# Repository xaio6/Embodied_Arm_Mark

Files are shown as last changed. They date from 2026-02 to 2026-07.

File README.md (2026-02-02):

# HorizonArm Mark 版本

欢迎使用 **HorizonArm Mark 版本**开发包。本文档是**根目录总入口**：用“学习路线”的方式，带你从 0 到 1 跑通示例，再按你的角色（控制/视觉/AI/仿真/交互）逐步深入，最终把 SDK 稳定集成进你的项目。

> 强烈建议：不要只“看文档”，要**边看边运行示例**。本仓库已经把“可复制、可运行、可扩展”的示例准备好了。

---

## 🎯 学习路线总览（按路线走，不迷路）

```text
第0步：了解项目结构（5分钟）
    ↓
第1步：环境准备与安装依赖（10分钟）
    ↓
第2步：SDK 理论学习（30分钟）
    ↓
第3步：5分钟跑通快速入门（5分钟）
    ↓
第4步：按角色选择深入学习路径（2-8小时）
    ↓
第5步：项目实践与工程化集成（持续迭代）
```

---

## 📂 第0步：了解项目结构（5分钟）

本仓库的“真正入口”在 `example/`：**示例 + 文档 + 学习路径**都在里面。

```text
Horizon_Arm_Mark/
├── example/                              ⭐ 从这里开始（示例与文档总入口）
│   ├── README.md                         - 示例总导航（第一次打开就看它）
│   ├── SDK完全介绍.md                     - SDK 架构与核心概念（强烈建议先看）
│   ├── 示例代码总导航.md                  - 更细粒度的示例索引与学习路径
│   ├── quickstart_guide.py               - 5分钟快速入门（强烈建议先跑）
│   ├── sdk_quickstart.py                 - 交互式完整示例（6轴/预设动作/夹爪等）
│   ├── control_sdk_examples/             - 控制相关教学示例（单电机/多机同步/IO/视觉/仿真/手柄）
│   ├── ai_sdk_examples/                  - AI 相关示例（LLM/ASR/TTS/多模态/智能对话）
│   ├── developer_tools/                  - 开发者工具（传感器监控/仿真滑块等）
│   ├── docs/                             - 文档中心（index.md 是总入口）
│   └── mkdocs.yml                        - 文档站点配置（如需自行构建）
│
├── Embodied_SDK/                          ⭐ 推荐开发入口（Python 源码，可直接读/改/引用）
│   ├── horizon_sdk.py                     - 顶层聚合入口（HorizonArmSDK）
│   ├── motion.py                          - 运动控制（关节/笛卡尔/预设动作/夹爪等）
│   ├── visual_grasp.py                    - 视觉抓取/跟随
│   ├── joycon.py                          - 手柄控制封装（如需）
│   ├── io.py                              - IO 控制
│   ├── digital_twin.py                    - MuJoCo 仿真接口（如需）
│   ├── ai.py                              - AI 封装（如需）
│   └── __init__.py                        - 常用导出（create_motor_controller 等）
│
├── Horizon_Core/                          🔒 核心驱动与算法（部分为二进制封装 .pyd）
│   ├── Control_SDK/                       - 控制核心与协议层
│   ├── AI_SDK/                            - AI 核心（providers/core/utils 等）
│   └── gateway.py                         - 常用网关入口（部分示例会引用）
│
├── config/                                ⚙️ 配置文件（电机/标定/URDF/AI/预设动作等）
│   ├── motor_config.json
│   ├── calibration_parameter.json
│   ├── embodied_config/preset_actions.json
│   ├── aisdk_config.yaml
│   └── urdf/mjmodel.xml                   - 仿真模型（MuJoCo）
│
├── requirements.txt                        📄 依赖清单（已按“默认必装/可选”分组）
└── README.md                               📖 你正在读的文档（Mark 版本总入口）
```

你需要记住的只有两句话：

- **想快速跑起来**：直接看并运行 `example/quickstart_guide.py`
- **想系统学/做项目**：从 `example/README.md` 与 `example/docs/index.md` 开始走路线

---

## 🔧 第1步：环境准备与安装依赖（10分钟）

### 1.1 环境要求

- **Python**：3.12+（本仓库示例与依赖分组以此为准）
- **操作系统**：Windows 10/11（也可 Ubuntu 20.04+ 纯脚本运行）
- **真实硬件（可选）**：OmniCAN（UCP 模式，电脑侧表现为串口）+ 机械臂驱动板/电机

### 1.2 安装依赖（推荐）

在项目根目录执行：

```bash
pip install -r requirements.txt
```

`requirements.txt` 的设计原则：

- **默认必装**：能跑通“控制 + 视觉”核心示例
- **可选依赖**：Joy-Con / AI / 语音 / MuJoCo / GUI / 可视化等，按需启用

> 如果你只想先控制机械臂、跑运动示例：默认安装即可；不要一上来就把所有可选功能都装齐。

### 1.3 Windows 下常见安装问题（可选项）

- **pyaudio（仅语音相关示例需要）**：部分环境需要额外步骤  
  参考 `requirements.txt` 里的说明（例如 `pipwin install pyaudio`）。

---

## 📚 第2步：SDK 理论学习（30分钟）

### 2.1 必读文档（强烈建议）

- **SDK 架构与示例索引**：`example/SDK完全介绍.md`
- **文档中心总入口**：`example/docs/index.md`

阅读目标（30 分钟内达成）：

- 知道推荐入口是 `Embodied_SDK`，顶层入口是 `HorizonArmSDK`
- 理解两套常用坐标/单位：  
  - 关节角：度（deg）  
  - 末端位置：毫米（mm）；末端姿态：度（deg）
- 知道你应该先跑哪些示例、下一步该学哪些模块文档

---

## 🚀 第3步：5分钟跑通快速入门（5分钟）

### 3.1 ⚠️ 安全第一（务必先读）

第一次上电、第一次跑控制脚本前，先看：

- `example/docs/safety.md`

其中最关键的一条（请务必理解）：

- **如果你的电机没有物理抱闸（刹车），严禁随意 `disable()` 失能**  
  正确做法通常是 **stop（停止运动）/disconnect（断开通信）**，而不是让机械臂“瞬间掉落”。

### 3.2 运行快速入门脚本

直接在根目录运行：

```bash
python example/quickstart_guide.py
```

你会做的事情（典型流程）：

- 输入/确认串口号（Windows 设备管理器里看到的 `COMx`）
- 连接电机（通常是 1-6 号关节；夹爪可能是 7 号，视你的硬件）
- 读取状态、执行小幅度运动验证链路

### 3.3 跑通后继续：完整交互示例

```bash
python example/sdk_quickstart.py
```

这个脚本更像“控制台版上位机”，适合用来：

- 复习关节运动 / 笛卡尔运动
- 测试夹爪与预设动作
- 在你写自己项目之前，先把基础能力跑顺

---

## 🎓 第4步：按角色选择深入学习路径（2-8小时）

> 更完整导航请直接看：`example/README.md` 与 `example/示例代码总导航.md`  
> 文档中心请看：`example/docs/index.md`

下面按真实开发角色给你“最短路径”，每一步都能落到仓库里**真实存在的文件**。

---

### 🔧 路径A：机械臂控制工程师（4-6小时）

**目标**：掌握电机控制、运动、同步控制、IO 联动，并具备工程化集成能力。

#### A1. 单电机与基础通信（30-60分钟）

- `example/control_sdk_examples/motor_usage_example.py`
- 完整参考（功能更多）：`example/test_interactive.py`

你需要掌握：

- 连接/断开（connect/disconnect）
- 停止（stop）与“失能（disable）”的安全区别（见 `example/docs/safety.md`）
- 位置/速度/力矩模式的基本用法（示例里都有）

#### A2. 6轴基础运动与预设动作（30-60分钟）

- `example/sdk_quickstart.py`
- 文档：`example/docs/motion.md`

你需要掌握：

- `move_joints`（关节空间）
- `move_cartesian`（笛卡尔空间）
- 预设动作的组织方式（`config/embodied_config/preset_actions.json`）

#### A3. 多电机同步（20-60分钟）

- 教学版：`example/control_sdk_examples/multi_motor_sync_example.py`
- 完整版：`example/test_multi_motor_sync.py`

你需要掌握：

- 同步控制的基本思想：一次性下发/触发/执行（示例会解释）
- 如何选择“教学版”与“完整版”（先学教学版，再看完整版）

#### A4. IO 集成（20-40分钟）

- `example/control_sdk_examples/io_control_example.py`
- 文档：`example/docs/io.md`

适用场景：

- 传感器触发（限位、光电、接近等）
- 执行器联动（继电器、气动、电磁阀、指示灯等）

#### A5. 工程化落地建议（你写项目时最常踩坑的点）

建议你在自己项目里做到：

- 把串口号、相机 ID、电机 ID 列表、速度/加速度、工作空间限制等全部做成可配置项
- 写“安全启动流程”：上电 → 自检 → 低速小幅度试动 → 正式运行
- 写“统一退出流程”：异常时 stop + disconnect（不要直接 disable）

---

### 👁️ 路径B：视觉应用开发者（3-5小时）

**目标**：掌握标定文件、像素到机械臂坐标、视觉抓取/跟随的基本流程，并能排查“抓不准”。

#### B1. 先把基础控制跑通（30分钟）

- `example/quickstart_guide.py`
- `example/control_sdk_examples/motor_usage_example.py`

#### B2. 视觉抓取示例（1-2小时）

- `example/control_sdk_examples/visual_grasp_example.py`
- 文档：`example/docs/vision.md`

你需要关注的配置与文件：

- `config/calibration_parameter.json`（标定参数）
- 视觉相关示例通常会做“自检”（是否存在标定文件等），建议先看输出再动手修改参数

#### B3. 常见问题与排查思路（很重要）

如果出现“抓取位置偏差大”，优先排查：

- 标定文件是否对应当前相机与安装位姿（换相机/换安装位置必须重标定或更新参数）
- TCP 偏移、抓取高度/接近高度是否合理（过低容易碰撞，过高会抓不到）
- 视觉输入的像素点是否来自同一分辨率/同一相机 ID

文档入口：

- `example/docs/troubleshooting.md`
- `example/docs/configuration.md`

---

### 🧠 路径C：AI 集成开发者（4-6小时）

**目标**：能跑通 AI 配置与示例，理解“AI 输出如何安全地驱动机械臂动作”，并能做基础的工程集成。

#### C1. 先理解配置（30-60分钟）

- `example/ai_sdk_examples/config_example.py`
- 配置文件：`config/aisdk_config.yaml`

#### C2. LLM / 多模态 / 语音（按需选择）

- LLM：`example/ai_sdk_examples/LLM_usage.py`
- 多模态：`example/ai_sdk_examples/multimodal_usage_example.py`
- 语音识别：`example/ai_sdk_examples/asr_usage_example.py`
- 语音合成：`example/ai_sdk_examples/tts_usage_example.py`
- 综合 Demo：
  - `example/ai_sdk_examples/smart_multimodal_chat_demo.py`
  - `example/ai_sdk_examples/smart_multimodal_voice_chat_demo.py`

#### C3. 具身智能（建议先在仿真验证，再上真机）

- 文档：`example/docs/embodied.md`

安全建议（强烈建议你遵守）：

- AI 输出必须做约束（速度、空间、姿态范围、动作类型白名单）
- 先在仿真/离线环境验证，再在真机小幅度、低速尝试

---

### 🎮 路径D：人机交互开发者（3-4小时）

**目标**：把“输入设备/交互逻辑/安全停止/状态显示”做成你能复用的交互组件。

仓库入口（按需选择）：

- 手柄文档：`example/docs/joycon.md`
- 手柄教学示例：`example/control_sdk_examples/joycon_control_example.py`
- 全功能控制台参考：`example/test_joycon_arm_control.py`
- 状态可视化：`example/test_joycon_display.py`

开发者工具（调试很有用）：

- `example/developer_tools/README.md`
- `example/developer_tools/joycon_sensor_display.py`

---

### 🎮 路径E：仿真开发者（1-2小时）

**目标**：在没有真实硬件时也能开发；在上真机前先验证轨迹/动作逻辑。

入口：

- 教学示例：`example/control_sdk_examples/digital_twin_example.py`
- 交互演示：`example/mujoco_control.py`
- 文档：`example/docs/simulation.md`

关键文件：

- `config/urdf/mjmodel.xml`

---

## 🛠️ 第5步：项目实践与工程化集成（持续）

这一部分是“从示例到你项目”的落地建议：字多但很实用，建议你在真正写业务代码前扫一遍。

---

### 5.1 推荐的项目集成方式（强烈建议照抄结构）

你可以在仓库根目录旁边新建自己的项目目录，例如：

```text
my_mark_project/
├── app/                         # 你的业务逻辑
│   ├── main.py
│   ├── robot/                   # 机械臂封装层（你自己写）
│   ├── vision/                  # 视觉封装层（你自己写）
│   └── io/                      # IO 封装层（你自己写）
├── configs/
│   └── config_local.yaml        # 你自己的部署参数（端口/相机ID/速度等）
└── README.md
```

并且把仓库里的 SDK 当作“依赖/子模块/同仓引用”，而不是把示例代码散落复制到各处。

---

### 5.2 你必须配置化的参数（不然一定会痛苦）

建议至少把这些参数全部配置化（配置文件/环境变量/命令行参数任选其一）：

- 串口号：`COMx`
- 电机 ID 列表：默认 1-6（夹爪可能是 7）
- 相机 ID：`camera_id`（默认 0）
- 最大速度、加速度、减速度（首次使用务必低速）
- 预设动作名称与对应关节角（`preset_actions.json`）
- 视觉抓取参数（抓取高度、接近高度、TCP 偏移等）
- 工作空间限制（半径/高度/禁区）

---

### 5.3 运行与部署（建议习惯性做的检查）

每次上线/每次更换环境，建议你都做一次“最小验证”：

1. 先跑 `example/quickstart_guide.py`（确认通信链路 OK）
2. 再跑 `example/sdk_quickstart.py`（确认 6 轴基本动作 OK）
3. 再跑你自己的业务脚本（逐步扩大动作范围）

为什么要这么做：

- 能快速区分是“硬件/连接问题”还是“你业务代码问题”
- 能避免“第一次就跑你的复杂业务”导致无法定位问题

---

### 5.4 故障排查的最短路径（别乱猜）

文档入口：

- `example/docs/troubleshooting.md`

最常见的 5 类问题与优先级：

1. **串口打不开**：端口号不对 / 被占用 / 设备驱动问题
2. **电机无响应**：ID 不对 / 供电问题 / 总线问题
3. **运动方向不对**：检查 `config/motor_config.json` 里的方向/减速比等
4. **视觉抓不准**：标定文件不匹配 / TCP 偏移不对 / 分辨率/相机 ID 不一致
5. **仿真起不来**：`mujoco` 未安装 / OpenGL 环境问题 / 模型文件缺失

---

## 📖 文档与资源索引（快速跳转）

### 你应该优先打开的 3 个入口

- `example/README.md`（示例总导航）
- `example/SDK完全介绍.md`（架构与核心概念）
- `example/docs/index.md`（文档中心总入口）

### 常用文档

- 安装：`example/docs/installation.md`
- 安全：`example/docs/safety.md`
- 快速入门：`example/docs/quickstart.md`
- 配置说明：`example/docs/configuration.md`
- API 参考：`example/docs/api_reference.md`
- API 详细：`example/docs/api_detailed.md`
- 故障排查：`example/docs/troubleshooting.md`

---

## 🧾 版本信息

- **版本**：Mark（Horizon_Arm2.0）
- **更新时间**：2026-02
- **维护**：HorizonArm Team

#

## 📊 学习进度自检表

根据您的学习目标，勾选已完成的项目：

### 🎯 基础掌握（所有开发者必须）

- [ ] 理解SDK架构和9个核心模块
- [ ] 成功连接一台电机
- [ ] 能够控制电机运动（速度/位置）
- [ ] 理解关节空间和笛卡尔空间
- [ ] 能够查阅示例代码并复用

### 🔧 控制工程师进阶

- [ ] 掌握单电机全部控制模式
- [ ] 实现多机同步控制
- [ ] 理解同步控制三阶段
- [ ] 集成IO传感器和执行器
- [ ] 能够调试电机参数（PID等）

### 👁️ 视觉开发者进阶

- [ ] 理解手眼标定原理
- [ ] 成功执行像素点抓取
- [ ] 实现视觉跟随功能
- [ ] 结合AI进行目标识别
- [ ] 能够独立进行相机标定

### 🤖 交互开发者进阶

- [ ] 配对并连接Joy-Con
- [ ] 实现手柄遥操作
- [ ] 配置自定义按键映射
- [ ] 实现IO联动控制
- [ ] 集成语音交互（可选）

### 🧠 AI开发者进阶

- [ ] 配置AI SDK
- [ ] 调用LLM API
- [ ] 实现多模态理解
- [ ] 集成语音识别和合成
- [ ] 实现AI驱动的机械臂控制

---

## 🆘 常见问题和解决方案

### Q1: 电机连接失败？

**检查清单：**
1. 串口号是否正确（设备管理器查看）
2. 电机ID是否正确
3. 电机是否上电
4. 没有其他程序占用串口

**参考：** `example/SDK完全介绍.md` 的"常见问题"部分或 `example/docs/troubleshooting.md`

### Q2: 多电机控制失败？

**解决方案：**
必须使用 `shared_interface=True`：
```python
for mid in [1, 2, 3, 4, 5, 6]:
    motor = create_motor_controller(motor_id=mid, shared_interface=True)
```

### Q3: 视觉抓取位置不准？

**检查：**
1. 是否完成手眼标定
2. 标定文件路径是否正确
3. 相机和机械臂位置是否改变

### Q4: 授权验证失败？

**联系技术支持获取授权文件**

---

## 📖 文档索引

### 核心文档

| 文档 | 位置 | 用途 |
|---|---|---|
| **开发者学习路线** | `开发者学习路线.md` | 本文档 - 完整学习路线 |
| **SDK完全介绍** | `example/SDK完全介绍.md` | SDK详细文档和架构说明 |
| **示例代码总导航** | `example/示例代码总导航.md` 或 `example/README.md` | 示例导航和快速开始 |
| **Control SDK指南** | `example/control_sdk_examples/README.md` | Control SDK学习路径 |
| **文档中心** | `example/docs/index.md` | 完整文档导航 |

### 示例代码

| 类型 | 位置 | 说明 |
|---|---|---|
| 快速入门 | `example/quickstart_guide.py` | 5分钟体验 |
| Control SDK | `example/control_sdk_examples/` | 7个教学示例 |
| AI SDK | `example/ai_sdk_examples/` | 10+个AI示例 |
| 完整参考 | `example/test_*.py` | 40+功能完整版 |
| 开发工具 | `example/developer_tools/` | 调试工具 |

---

## 🎓 学习建议

### 时间安排

- **兼职学习**：每天1-2小时，1周内完成基础路径
- **全职学习**：每天4-6小时，2-3天内完成基础路径
- **深入掌握**：持续2-4周，完成所有进阶内容

### 学习方法

1. **理论与实践结合**
   - 先看文档理解原理
   - 立即运行示例验证
   - 修改参数加深理解

2. **循序渐进**
   - 不要跳过基础内容
   - 按推荐顺序学习
   - 每个示例都要运行

3. **查看源码**
   - `Embodied_SDK/` 源码可以查看
   - 理解API实现逻辑
   - 学习代码组织方式

4. **动手实践**
   - 完成自检表中的所有项目
   - 尝试实现小项目
   - 遇到问题主动排查

---

## 📞 技术支持

遇到问题？按以下顺序解决：

1. **查看文档** - `example/SDK完全介绍.md` 的常见问题部分
2. **查看故障排除** - `example/docs/troubleshooting.md` 详细的故障诊断
3. **运行自检** - 相关示例的系统自检功能
4. **查看完整示例** - `example/test_interactive.py` 等完整版参考
5. **使用调试工具** - `example/developer_tools/` 下的专业工具
6. **联系技术支持** - 提供详细错误信息和日志

---

## 🎯 学习目标检验

### 基础能力（所有开发者必备）

完成基础学习后，您应该能够：

- ✅ **连接控制** - 独立连接和控制单个或多个电机
- ✅ **理解架构** - 理解SDK的模块组织和调用关系
- ✅ **查阅文档** - 能够快速查阅文档找到需要的API
- ✅ **复用代码** - 复用示例代码到自己的项目中
- ✅ **排查问题** - 能够根据错误信息初步排查问题
- ✅ **配置管理** - 理解和修改配置文件

### 进阶能力（根据专业方向）

#### 🔧 控制工程师
- ✅ 掌握三种电机控制模式（速度/位置/力矩）
- ✅ 实现多电机精确同步控制
- ✅ 集成IO传感器和执行器
- ✅ 调试和优化运动参数（PID等）
- ✅ 处理异常情况和安全保护

#### 👁️ 视觉开发者
- ✅ 理解手眼标定原理和流程
- ✅ 实现像素坐标到机械臂坐标转换
- ✅ 完成视觉引导抓取任务
- ✅ 集成AI进行目标识别和分类
- ✅ 优化视觉处理性能

#### 🤖 交互开发者
- ✅ 配置和使用Joy-Con手柄控制
- ✅ 自定义按键映射和控制参数
- ✅ 实现IO联动和传感器触发
- ✅ 集成语音识别和合成（可选）
- ✅ 设计直观的人机交互界面

#### 🧠 AI开发者
- ✅ 配置和调用LLM API
- ✅ 实现多模态理解（视觉+语言）
- ✅ 集成语音识别和语音合成
- ✅ 实现AI驱动的机械臂控制
- ✅ 设计具身智能应用

### 专家能力（高级开发者目标）

- ✅ **深入理解** - 理解SDK底层实现原理和通信协议
- ✅ **扩展开发** - 自定义扩展功能和新模块
- ✅ **性能优化** - 优化系统性能和稳定性
- ✅ **系统集成** - 集成到复杂的生产系统中
- ✅ **架构设计** - 设计大型机械臂应用的软件架构
- ✅ **问题诊断** - 快速诊断和解决复杂问题

---

## 📈 进阶学习资源

### 源码学习
- **Embodied_SDK/** - SDK源码可查看，学习实现原理
- **关键文件**:
  - `motion.py` - 运动学算法实现
  - `visual_grasp.py` - 手眼标定和坐标转换
  - `joycon.py` - 手柄控制映射逻辑
  - `digital_twin.py` - MuJoCo仿真接口

### 配置文件
- **config/** - 各种配置示例
  - `motor_config.json` - 电机参数配置
  - `calibration_parameter.json` - 标定参数
  - `aisdk_config.yaml` - AI服务配置
  - `preset_actions.json` - 预设动作定义

### 完整示例
- **test_interactive.py** - 40+功能的完整单电机工具
- **test_multi_motor_sync.py** - 26+功能的多机同步工具
- **sdk_quickstart.py** - 完整的机械臂控制框架

---

## 🎓 认证与考核（可选）

### 基础认证
完成以下任务即可认为掌握基础能力：
1. 独立编写程序连接并控制6个电机
2. 实现多电机同步运动
3. 集成一个IO传感器
4. 处理连接失败等异常情况

### 进阶认证
根据您的专业方向完成对应项目：
- **控制工程师**: 实现一个完整的自动化流程
- **视觉开发者**: 实现一个视觉引导抓取任务
- **交互开发者**: 实现一个手柄遥操作系统
- **AI开发者**: 实现一个自然语言控制的机械臂

---

## 🌟 成功案例参考

### 案例1：自动化生产线
- **应用**: 产品分拣和装配
- **技术栈**: 电机控制 + IO联动 + 视觉检测
- **学习时间**: 2周
- **关键技术**: 多机同步、IO触发、位置精度控制

### 案例2：智能服务机器人
- **应用**: 物品识别和递送
- **技术栈**: 视觉抓取 + AI识别 + 语音交互
- **学习时间**: 3周
- **关键技术**: 手眼标定、目标检测、自然语言理解

### 案例3：远程遥操作系统
- **应用**: 危险环境作业
- **技术栈**: 手柄控制 + 视觉反馈 + 力反馈
- **学习时间**: 2周
- **关键技术**: 实时控制、视频传输、安全保护

### 案例4：算法研究平台
- **应用**: 运动规划算法验证
- **技术栈**: 数字孪生 + 轨迹规划
- **学习时间**: 1周
- **关键技术**: MuJoCo仿真、逆运动学、碰撞检测

---

## 💪 持续成长建议

### 技术提升
- 📚 **阅读论文** - 了解机械臂和机器人领域前沿技术
- 💻 **开源贡献** - 参与相关开源项目
- 🎯 **实战项目** - 完成实际应用项目积累经验
- 🤝 **技术交流** - 参加技术社区和开发者交流

### 知识扩展
- **机械臂运动学** - 深入学习正逆运动学理论
- **计算机视觉** - 学习图像处理和目标识别
- **控制理论** - 学习PID控制和高级控制算法
- **AI技术** - 学习深度学习和强化学习

### 职业发展
- **机械臂应用工程师** - 负责机械臂系统集成和应用开发
- **机器人视觉工程师** - 专注于视觉引导和AI识别
- **自动化系统架构师** - 设计大型自动化系统
- **具身智能研究员** - 研究AI与机器人结合

---

**版本**: Mark  
**更新日期**: 2026-1  
**维护**: HorizonArm  

祝您学习顺利，成为优秀的机械臂开发者！🚀  
如有任何问题，欢迎查阅文档或联系技术支持。

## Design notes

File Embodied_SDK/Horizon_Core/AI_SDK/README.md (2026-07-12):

# AI_SDK 开发者文档

AI_SDK 提供一个统一、简洁的 Python 接口，聚合多家 AI 能力：
- LLM 大语言模型（聊天/流式/异步/上下文会话）
- ASR 语音识别（文件/麦克风/实时流/关键词唤醒）
- TTS 语音合成（文件/扬声器/流式边听边说）
- 多模态（图像/视频理解，多图像分析）
- 智能对话（LLM + TTS 一体化）

面向“应用层开发者”：你只需调用 SDK 方法，不需要了解底层供应商的差异和协议细节。

---

## 安装与环境

- 推荐直接使用项目根目录的依赖：
  ```bash
  pip install -r requirements.txt
  ```
- Windows 安装 `pyaudio` 可能需要：
  ```bash
  pip install pipwin && pipwin install pyaudio
  ```

## 配置（强烈建议用环境变量注入密钥）

默认读取 `config/aisdk_config.yaml`，也可传入 `config_dict`。建议将密钥以环境变量形式配置，例如：

```yaml
providers:
  alibaba:
    api_key: ${ALI_API_KEY}
    default_params:
      max_tokens: 2000
      temperature: 0.7
      top_p: 0.8
    enabled: true
  deepseek:
    api_key: ${DEEPSEEK_API_KEY}
    default_params:
      max_tokens: 2000
      temperature: 0.7
      top_p: 1.0
    enabled: true
```

- 支持覆盖的常见配置：
  - `request`: `timeout`, `max_retries`, `retry_delay`
  - `logging`: `level`, `file`, `max_size`, `backup_count`
  - `session`: `default_max_history`, `max_sessions`
  - `providers.*.default_params`: 每家默认模型参数（`temperature`, `top_p`, `max_tokens` 等）

---

## 快速开始

```python
from Embodied_SDK import AISDK

sdk = AISDK()  # 默认读取 config/aisdk_config.yaml

# 1) 基础聊天（同步）
resp = sdk.chat(provider="alibaba", model="qwen-turbo", prompt="你好")
print(resp)

# 2) 流式聊天（同步流）
for chunk in sdk.chat("alibaba", "qwen-turbo", "讲个笑话", stream=True):
    print(chunk, end="")

# 3) 上下文对话（自动管理历史）
sdk.chat("alibaba", "qwen-turbo", "我叫张三", use_context=True)
name = sdk.chat("alibaba", "qwen-turbo", "我叫什么？", use_context=True)

# 4) 异步调用（需在异步环境中）
# response = await sdk.chat("alibaba", "qwen-turbo", "你好", async_mode=True)
```

---

## ASR 语音识别

```python
# 文件识别
r = sdk.asr(provider="alibaba", mode="file", audio_file="audio.wav")

# 麦克风识别（duration: 秒）
r = sdk.asr("alibaba", "microphone", duration=5)

# 实时流识别（传入音频流/生成器）
for out in sdk.asr("alibaba", "stream", audio_stream=my_stream()):
    print(out)

# 关键词检测（流式唤醒）
for out in sdk.asr("alibaba", "keyword", keywords=["你好", "小助手"]):
    if out.get("success"):
        print("唤醒词：", out.get("keyword_detected"))
```

常用参数：`audio_file`、`duration`、`audio_stream`、`keywords`、`async_mode` 等。

---

## TTS 语音合成

```python
# 文本转语音 → 保存到文件
r = sdk.tts(provider="alibaba", mode="file", text="你好世界", output_file="out.mp3")

# 文本转语音 → 扬声器播放
r = sdk.tts("alibaba", "speaker", "欢迎使用AI_SDK")

# 流式合成（配合LLM流式输出或自定义生成器）
def text_gen():
    yield "今天天气"
    yield "不错"
for r in sdk.tts("alibaba", "stream", text_gen()):
    print("chunk done")
```

常用参数：`voice`, `sample_rate`, `format`, `speaker`, `prosody` 等（依具体提供商/模型）。

---

## 多模态（图像/视频）

```python
# 图像理解
r = sdk.multimodal(provider="alibaba", mode="image", prompt="描述这张图", image_path="image.jpg")

# 视频分析
r = sdk.multimodal("alibaba", "video", "这个视频讲了什么", video_path="video.mp4")

# 多图像分析
r = sdk.multimodal("alibaba", "multiple_images", "比较这些图片", image_paths=["a.jpg", "b.jpg"])  # 通过kwargs传入
```

常用参数：`model`（如 `qwen-vl-max-latest`）、`temperature`、`max_tokens`、`fps`（视频抽帧）等。

---

## 智能对话（LLM + TTS 一体化）

```python
# 直接问答并语音播放
o = sdk.smart_chat(
    prompt="请用两句话介绍一下你自己",
    llm_provider="alibaba", llm_model="qwen-turbo",
    tts_provider="alibaba", tts_model="sambert-zhichu-v1",
    tts_mode="speaker",  # 或 "file"/"stream"
    use_context=False,
)
print(o)
```

进阶：`smart_multimodal_chat`（图像/视频 + 文本）、`smart_voice_chat`（语音端到端）、`smart_multimodal_voice_chat`。

---

## 会话与上下文

```python
# 使用默认全局历史
sdk.chat("alibaba", "qwen-turbo", "记住我叫王五", use_context=True)

# 自定义会话ID
a_id = "user_A"
sdk.create_session(session_id=a_id, max_history=30)
sdk.chat("alibaba", "qwen-turbo", "我喜欢足球", use_context=True, session_id=a_id)

# 历史管理
hist = sdk.get_conversation_history(session_id=a_id)
sdk.set_conversation_history(hist[-10:], session_id=a_id)
sdk.clear_conversation_history(session_id=a_id)

# 会话管理
sdk.list_sessions()
sdk.delete_session(a_id)
```

---

## 切换提供商与模型

```python
# 查看可用提供商
deps = sdk.get_available_providers()

# 查看提供商可用模型
models = sdk.get_provider_models("alibaba")

# 在同一套API下切换到DeepSeek
o = sdk.chat(provider="deepseek", model="deepseek-chat", prompt="Explain RAG in 1 sentence")
```

你也可以在 `config/aisdk_config.yaml` 中启用/禁用提供商或修改 `default_params`。

---

## 异步与流式

- 任意接口均可设置 `async_mode=True` 获得 `await` 版本
- LLM 与 TTS 支持 `stream=True` 或对应的流式生成器

```python
# 异步流式
# async for chunk in sdk.chat("alibaba", "qwen-turbo", "你好", stream=True, async_mode=True):
#     print(chunk)
```

---

## 错误处理与日志

```python
from Embodied_SDK.Horizon_Core.AI_SDK.utils.exceptions import AISDKException

try:
    sdk.chat("alibaba", "qwen-turbo", "hi")
except AISDKException as e:
    print("AI错误:", str(e))
except Exception as e:
    print("其他错误:", str(e))
```

- 日志：在 `config/aisdk_config.yaml` 的 `logging` 中配置输出文件、级别与大小滚动。

---

## 目录结构（简要）

```
AI_SDK/
├── __init__.py                 # AISDK 主入口（统一API）
├── core/                       # 领域处理器（llm/asr/tts/multimodal/smart_chat/session等）
├── services/                   # 面向AISDK的服务封装
├── providers/                  # 各家厂商适配（alibaba、deepseek等）
├── utils/                      # 异常、工具、格式化等
└── README.md                   # 本文档
```

---

## 最佳实践

- 使用环境变量注入 API Key（不要把密钥提交到仓库）：
  - Windows PowerShell: `setx ALI_API_KEY "your_key"`
  - Linux/macOS: `export ALI_API_KEY=your_key`
- 覆盖默认配置：初始化时传 `config_dict` 或修改 YAML 中的 `default_params`。
- 控制并发与重试：通过 `request.max_retries`、`timeout`、`retry_delay` 调整。
- 资源清理：处理长会话或高并发时，定期 `list_sessions()` + 清理历史。

---

## 许可证与版本

- 许可证：MIT
- 当前版本：见 `AI_SDK/__init__.py` 中的 `__version__`

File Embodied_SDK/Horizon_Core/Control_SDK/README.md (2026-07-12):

# ZDT闭环驱动板Python SDK（UCP硬件保护版）

这是一个用于控制ZDT闭环驱动板的Python SDK，通过ESP32+CAN硬件保护板进行控制，PC端使用UCP串口协议通信。

## 特性

- 🚀 **简单易用的API** - 提供直观的高级接口
- 🔧 **完整的功能支持** - 支持所有ZDT驱动板功能
- 🔄 **多种控制模式** - 力矩模式、速度模式、位置模式
- 🔒 **UCP硬件保护** - 协议封装在ESP32固件中，保护知识产权
- 📡 **串口通信** - 仅需USB串口连接，无需python-can
- 🎯 **精确控制** - 支持梯形曲线运动规划
- 🏠 **回零功能** - 完整的原点回零支持
- 🔗 **多机同步控制** - 支持真正的多电机同步运动，基于官方上位机同步机制
- 🛡️ **错误处理** - 完善的异常处理机制
- 📊 **实时监控** - 实时状态和参数监控
- 🧪 **交互式测试** - 内置多种测试工具

## 硬件要求

- 闭环驱动板
- ESP32+CAN硬件保护板（UCP模式）
- USB串口线
- CAN总线速率设置为500K（驱动板侧）

## 安装

### 1. 安装依赖

```bash
pip install pyserial
```

### 2. 下载SDK
将`Control_Core`文件夹复制到您的项目目录中。

## 快速开始

### 基础控制示例

```python
from Control_Core import ZDTMotorController

# 创建电机控制器（UCP串口，默认115200波特率）
with ZDTMotorController(motor_id=1, port="COM31", baudrate=115200) as motor:
    # 使能电机
    motor.enable()
    
    # 位置控制
    motor.move_to_position(90.0, speed=200)
    motor.wait_for_position()
    
    # 速度控制
    motor.set_speed(100)
    
    # 获取状态
    position = motor.get_position()
    speed = motor.get_speed()
    print(f"位置: {position:.2f}度, 速度: {speed:.2f}RPM")
```

### 多机同步控制示例

```python
from Control_Core import ZDTMotorController

# 多电机（同一串口自动走连接池共享）
motor1 = ZDTMotorController(motor_id=1, port="COM31")
motor2 = ZDTMotorController(motor_id=2, port="COM31")

motor1.connect()
motor2.connect()

controllers = {1: motor1, 2: motor2}

# Y42聚合多机同步（官方推荐）
ZDTMotorController.y42_sync_enable(controllers, enabled=True)
ZDTMotorController.y42_sync_position(controllers, targets={1: -3600, 2: 7200}, speed=1000)
```

## 测试工具

### 1. 单电机测试工具

```bash
python test_control_sdk_ucp.py
```

功能包括：
- 📡 连接管理（自动或手动配置）
- 🔋 基础控制（使能、失能、停止）
- 📊 状态读取（位置、速度、温度等）
- 🏃 运动控制（速度、位置、力矩模式）
- 🏠 回零功能（触发回零、参数设置）
- 🔧 工具功能（位置清零、解除堵转保护）
- 📝 日志级别设置

### 2. 多机同步控制测试工具

```bash
python test_multi_motor_sdk.py
```

**核心特性**：
- 🔄 **Y42聚合多机同步** - 一次UCP通信完成多电机同步
- 🔗 **连接池共享** - 多个电机共享同一串口连接
- 🎯 **同步运动配置** - 支持位置/速度/使能同步
- 📊 **实时监控** - 串行状态读取，避免通信冲突
- 🚀 **快速测试** - 一键执行示例同步运动

## API文档

### 主要类

#### ZDTMotorController
主要的电机控制器类，提供所有控制功能。

```python
motor = ZDTMotorController(
    motor_id=1,                    # 电机ID (0=广播, 1-255=单机)
    port="COM31",                  # 串口号
    baudrate=115200                # 串口波特率
)
```

### 基础控制方法

连接/控制器

| 方法 | 说明 |
|---|---|
| `connect(motor_id=None)` | 连接UCP串口并绑定电机 ID（未在构造中提供时需在此指定） |
| `disconnect()` | 断开连接并释放共享/私有接口资源 |
| `set_motor_id(motor_id)` | 动态切换当前控制的电机地址（0=广播，1-255=单机） |
| `send_broadcast_command(command_data)` | 以广播地址(0)下发命令，不等待响应 |
| `multi_motor_command(per_motor_commands, expected_ack_motor_id=1, timeout=1.0, wait_ack=True, mode=None)` | Y42聚合多机命令（高级用法）；单次调用仅允许控制类或读取类之一，禁止混合 |
| `control_actions.sync_motion()` | 旧SLCAN同步触发（兼容保留，不推荐） |

基础控制（ControlActionsModule / TriggerActionsModule）

| 方法 | 说明 |
|---|---|
| `enable(multi_sync=False)` | 使能电机（可带多机同步标志） |
| `disable(multi_sync=False)` | 失能电机（可带多机同步标志） |
| `stop(multi_sync=False)` | 立即停止（可带多机同步标志） |
| `emergency_stop()` | 紧急停止（先停再失能，确保安全） |
| `clear_position()` | 将当前机械角度清零为 0° |
| `release_stall_protection()` | 解除堵转保护状态 |
| `trigger_encoder_calibration()` | 触发编码器校准流程 |

运动控制（ControlActionsModule）

| 方法 | 说明 |
|---|---|
| `set_torque(current, current_slope=DEFAULT_CURRENT_SLOPE, multi_sync=False)` | 力矩模式，单位 mA，支持正负方向；`current_slope` 为电流斜率 |
| `set_speed(speed, acceleration=DEFAULT_ACCELERATION, multi_sync=False)` | 速度模式，速度单位 RPM（可正负），加速度单位 RPM/s |
| `move_to_position(position, speed=DEFAULT_SPEED, is_absolute=False, multi_sync=False, timeout=1.0)` | 直通限速位置模式，位置单位度；`is_absolute=True` 为绝对位置，默认相对 |
| `move_to_position_trapezoid(position, max_speed=DEFAULT_SPEED, acceleration=DEFAULT_ACCELERATION, deceleration=DEFAULT_ACCELERATION, is_absolute=False, multi_sync=False, timeout=1.0)` | 梯形曲线位置模式，含独立加减速度限制 |

回零（HomingCommandsModule / ControlActionsModule）

| 方法 | 说明 |
|---|---|
| `start_homing(homing_mode=None, multi_sync=False)` | 开始回零；不指定则就近回零（见 `Parameters.HOMING_MODE_*`） |
| `force_stop_homing()` / `stop_homing()` | 强制停止回零流程 |
| `set_zero_position(save_to_chip=True)` | 将当前位置设为零点，可选择保存至芯片 |
| `modify_homing_parameters(...)` | 修改回零参数（模式、方向、速度、超时、碰撞检测、是否自启等） |
| `get_homing_status() -> HomingStatus` | 获取回零状态标志（编码器就绪、是否在回零、是否失败等） |
| `wait_for_homing_complete(timeout=30.0, check_interval=0.5) -> bool` | 阻塞等待回零完成/失败 |
| `is_homing_in_progress() -> bool` / `is_homing_failed() -> bool` / `is_encoder_ready() -> bool` | 回零便利查询 |

读取与监控（ReadParametersModule）

| 方法 | 说明 |
|---|---|
| `get_motor_status() -> MotorStatus` | 基本状态（使能/到位/堵转/堵转保护） |
| `get_position() -> float` | 实时位置（度） |
| `get_speed() -> float` | 实时转速（RPM） |
| `get_position_error() -> float` | 位置误差（度） |
| `get_temperature() -> float` | 驱动器温度（°C） |
| `get_bus_voltage() -> float` | 总线电压（V） |
| `get_current() -> float` | 相电流（A） |
| `get_bus_current() -> float` | 总线平均电流（A） |
| `get_version() -> Dict` | 固件/硬件版本（解析成人类可读） |
| `get_resistance_inductance() -> Dict` | 相电阻/相电感（含原始单位与换算） |
| `get_target_position() -> float` | 目标位置（度） |
| `get_realtime_target_position() -> float` | 实时设定目标位置（度） |
| `get_encoder_raw() -> float` | 编码器原始度数（0-16383→0-360°） |
| `get_encoder_calibrated() -> float` | 线性化后编码器度数（0-65535→0-360°） |
| `get_pulse_count() -> int` | 实时脉冲数 |
| `get_input_pulse() -> int` | 输入脉冲数 |
| `get_status_info() -> Dict` | 汇总常用状态信息（容错聚合） |
| `get_drive_parameters() -> DriveParameters` | 驱动配置全集（新增） |
| `get_system_status() -> SystemStatus` | 系统状态全集（含标志位展开，新增） |

参数修改（ModifyParametersModule）

| 方法 | 说明 |
|---|---|
| `modify_drive_parameters(params, save_to_chip=True)` / `set_drive_parameters(params, save_to_chip=True)` | 应用驱动参数（可选择保存至芯片） |
| `modify_drive_parameters_with_validation(params, save_to_chip=True)` | 带参数校验的驱动参数应用 |
| `create_default_drive_parameters()` / `create_open_loop_drive_parameters()` / `create_high_precision_drive_parameters()` | 提供常用预设，返回 `DriveParameters` |
| `modify_control_mode(control_mode, save_to_chip=True)` | 修改控制模式（0=开环，1=闭环FOC） |
| `modify_current_limits(open_loop_current=None, closed_loop_max_current=None, save_to_chip=True)` | 修改开环/闭环电流限制（mA） |
| `modify_speed_limit(max_speed_limit, save_to_chip=True)` | 修改最大转速限制（RPM） |
| `modify_stall_protection(enabled, speed_threshold=None, current_threshold=None, time_threshold=None, save_to_chip=True)` | 修改堵转保护启用与阈值 |
| `modify_communication_settings(uart_baudrate=None, can_baudrate=None, save_to_chip=True)` | 修改 UART/CAN 速率选项 |
| `validate_drive_parameters(params)` | 对 `DriveParameters` 进行范围/一致性检查 |
| `get_baudrate_options() -> dict` | UART/CAN 速率选项映射表 |
| `set_pid_parameters(...)` | 设置 PID（占位；当前以日志提示为主） |
| `set_baudrate(baudrate)` / `set_acceleration_limits(max_acceleration)` / `set_speed_limits(max_speed)` / `set_current_limits(max_current)` / `set_homing_parameters(...)` / `set_encoder_parameters(...)` | 兼容占位接口（日志提示为主，协议按后续实现） |

> 推荐使用 `ZDTMotorController.y42_sync_enable / y42_sync_position / y42_sync_speed` 进行多机同步，效率更高且已充分测试。

### 状态查询方法

| 方法 | 说明 |
|---|---|
| `get_position()` | 获取当前位置(度) |
| `get_speed()` | 获取当前转速(RPM) |
| `get_temperature()` | 获取驱动器温度(°C) |
| `get_bus_voltage()` | 获取总线电压(V) |
| `get_current()` | 获取相电流(A) |
| `get_motor_status()` | 获取电机状态 |
| `get_status_info()` | 获取完整状态信息 |
| `get_drive_parameters()` | 获取驱动参数（新增） |
| `get_system_status()` | 获取完整系统状态（新增） |

### 回零控制方法

| 方法 | 说明 |
|---|---|
| `set_zero_position()` | 设置当前位置为零点 |
| `trigger_homing(mode=None, homing_mode=None, multi_sync=False)` | 触发回零（推荐使用 `mode` 参数） |
| `force_stop_homing()` | 强制停止回零 |
| `wait_for_homing_complete()` | 等待回零完成 |

#### 回零模式与参数

- 新增模式（API 传参）：
  - `homing_mode=4` 回到绝对位置坐标零点
  - `homing_mode=5` 回到上次掉电位置角度
- `multi_sync` 已弃用，仅为兼容保留；推荐单机或使用Y42同步控制流程。
- 注意：使用 `trigger_homing(mode: int)` 即可，接线/参数需符合各回零模式要求。

### 触发动作（新增）

```python
# 紧急停止（立即停止电机并进入安全状态）
motor.trigger_actions.emergency_stop()

# 编码器校准
after_ok = motor.trigger_actions.trigger_encoder_calibration()

# 清零位置
motor.trigger_actions.clear_position()

# 解除堵转保护
motor.trigger_actions.release_stall_protection()

# 恢复出厂设置（谨慎执行）
motor.trigger_actions.factory_reset()
```

### 便捷方法

| 方法 | 说明 |
|---|---|
| `is_enabled()` | 检查电机是否使能 |
| `is_in_position()` | 检查电机是否到位 |
| `is_stalled()` | 检查电机是否堵转 |
| `wait_for_position()` | 等待电机到位 |

## 多机同步控制详解

### 同步机制（UCP/Y42聚合模式）

- **Y42聚合（推荐）**：一次UCP通信下发多电机命令，硬件级同步启动。
- **广播/同步标志（兼容）**：旧SLCAN方式保留，仅作兼容，不建议新项目使用。

### 同步控制步骤

```python
# 1. 创建控制器并连接
motor1 = ZDTMotorController(motor_id=1, port="COM31")
motor2 = ZDTMotorController(motor_id=2, port="COM31")

motor1.connect()
motor2.connect()

controllers = {1: motor1, 2: motor2}

# 2. Y42同步使能
ZDTMotorController.y42_sync_enable(controllers, enabled=True)

# 3. Y42同步位置
ZDTMotorController.y42_sync_position(
    controllers,
    targets={1: -3600, 2: 7200},
    speed=1000
)
```

### 支持的同步运动类型

- **位置同步**：`y42_sync_position`
- **速度同步**：`y42_sync_speed`
- **同步使能/失能**：`y42_sync_enable`

## 通信协议

本文面向应用层开发者，底层协议细节省略。UCP模式下，ZDT协议封装在ESP32固件中，PC端通过串口与ESP32通信。

## 硬件配置

### ZDT驱动板设置
1. **P_Serial设置**: 必须设置为`CAN1_MAP`
2. **CAN速率**: 设置为500K
3. **电机ID**: 设置为1-255之间的唯一值（多机时每个电机ID必须不同）
4. **接线**: 确保CAN_H和CAN_L正确连接

### 多机连接示例
```
电脑(COM31) ←→ ESP32+CAN硬件板 ←→ CAN总线 ←→ ZDT驱动板1(ID=1)
                                      ├→ ZDT驱动板2(ID=2)
                                      └→ ZDT驱动板N(ID=N)
```

## 错误处理

SDK提供了完善的异常处理机制：

```python
from Control_Core import (
    MotorNotEnabledException, 
    StallProtectionException,
    TimeoutException,
    CANInterfaceException
)

try:
    motor.move_to_position(180)
except MotorNotEnabledException:
    print("电机未使能，请先使能电机")
    motor.enable()
except StallProtectionException:
    print("电机堵转，解除保护")
    motor.release_stall_protection()
except TimeoutException:
    print("通信超时")
except CANInterfaceException as e:
    print(f"CAN接口错误: {e}")
```

## 常见问题

### Q: 连接失败怎么办？
A: 检查以下项目：
1. 串口号是否正确（通过设备管理器确认）
2. 是否有其他程序占用串口
3. ESP32硬件板是否正确上电
4. ZDT驱动板是否正确上电且CAN接线正常
5. P_Serial是否设置为CAN1_MAP

### Q: 电机不响应怎么办？
A: 检查以下项目：
1. 电机ID是否正确
2. CAN总线连接是否正常
3. 驱动板CAN速率是否为500K
4. 是否先使能了电机

### Q: 多机同步不工作怎么办？
A: 检查以下项目：
1. 每个电机的ID是否唯一且正确
2. 是否使用 `y42_sync_enable/y42_sync_position/y42_sync_speed`
3. 所有电机是否都已使能
4. CAN总线连接是否稳定

### Q: 如何调试通信问题？
A: 
1. 使用多机测试工具进行基础连通性检查
2. 分步连接测试逐个检查电机
3. 设置DEBUG日志级别：
```python
from Control_Core import setup_logging
import logging

setup_logging(logging.DEBUG)
```

### Q: 状态读取显示不了怎么办？
A: 
1. 使用"简化状态检查"功能，只读取最基本信息
2. 检查是否有多个程序同时访问CAN总线
3. 确认电机通信正常（使用单电机测试）

## 示例代码

### 完整的多机同步控制示例

```python
from Control_Core import ZDTMotorController, setup_logging
import logging
import time

# 启用详细日志
setup_logging(logging.INFO)

def multi_motor_sync_demo():
    """多机同步控制演示"""
    
    # 创建控制器
    motor1 = ZDTMotorController(motor_id=1, port="COM31")
    motor2 = ZDTMotorController(motor_id=2, port="COM31")
    
    try:
        # 连接串口
        print("连接串口...")
        motor1.connect()
        motor2.connect()
        
        # 使能电机
        print("使能电机...")
        controllers = {1: motor1, 2: motor2}
        ZDTMotorController.y42_sync_enable(controllers, enabled=True)
        time.sleep(1)
        
        # 读取初始位置
        pos1 = motor1.read_parameters.get_position()
        pos2 = motor2.read_parameters.get_position()
        print(f"初始位置 - 电机1: {pos1:.2f}°, 电机2: {pos2:.2f}°")
        
        # 配置并触发同步运动
        print("配置同步运动...")
        print("  电机1: 位置模式 -3600°")
        print("  电机2: 位置模式 7200°")
        
        print("触发同步运动...")
        ZDTMotorController.y42_sync_position(
            controllers,
            targets={1: -3600, 2: 7200},
            speed=1000
        )
        
        # 监控运动过程
        print("监控运动过程...")
        start_time = time.time()
        while time.time() - start_time < 30:  # 最多监控30秒
            try:
                # 读取状态
                status1 = motor1.read_parameters.get_motor_status()
                status2 = motor2.read_parameters.get_motor_status()
                pos1 = motor1.read_parameters.get_position()
                pos2 = motor2.read_parameters.get_position()
                speed1 = motor1.read_parameters.get_speed()
                speed2 = motor2.read_parameters.get_speed()
                
                # 显示状态
                elapsed = time.time() - start_time
                print(f"[{elapsed:.1f}s] 电机1: {pos1:.1f}° {speed1:.0f}RPM {'到位' if status1.in_position else '运动中'}")
                print(f"[{elapsed:.1f}s] 电机2: {pos2:.1f}° {speed2:.0f}RPM {'到位' if status2.in_position else '运动中'}")
                
                # 检查是否都到位
                if status1.in_position and status2.in_position:
                    print("✅ 所有电机已到位，同步运动完成!")
                    break
                    
                time.sleep(2)  # 2秒更新一次
                
            except Exception as e:
                print(f"状态读取错误: {e}")
                time.sleep(1)
        
        # 显示最终位置
        final_pos1 = motor1.read_parameters.get_position()
        final_pos2 = motor2.read_parameters.get_position()
        print(f"最终位置 - 电机1: {final_pos1:.2f}°, 电机2: {final_pos2:.2f}°")
        
    except Exception as e:
        print(f"错误: {e}")
    finally:
        # 断开连接
        motor1.disconnect()
        motor2.disconnect()
        print("✓ 已断开连接")

if __name__ == "__main__":
    multi_motor_sync_demo()
```

## 版本历史

- **v1.0.0** - 初始版本，支持SLCAN通信协议
- **v1.1.0** - 添加多机同步控制功能
  - 真正的多机同步控制，基于官方上位机同步机制
  - 多机同步测试工具（旧脚本）
  - 串行状态读取，避免CAN通信冲突
  - CAN总线诊断和分步连接测试功能
  - 完善的错误处理和日志系统
- **v1.2.0**
  - 模块化架构完善（控制/读取/修改/回零/触发）
  - 新增驱动参数读写（`DriveParameters`）
  - 新增系统状态读取（`SystemStatus`）
  - 新增触发动作（`emergency_stop` 等）
- **v2.0.0（当前）**
  - 引入UCP硬件保护模式（ESP32固件封装ZDT协议）
  - 无需python-can，仅依赖pyserial
  - Y42聚合多机同步（`y42_sync_*`）

## 许可证

本项目采用MIT许可证。

## 技术支持

如有问题或建议，请联系技术支持。

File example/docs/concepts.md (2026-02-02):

# 核心概念

本页用于统一 `Embodied_SDK` / `Control_SDK` / 示例脚本中的术语与单位，避免“同一个概念多个叫法”导致误用。

---

## 1. 分层结构（建议理解方式）

- **Control_SDK（底层）**：单电机/多电机控制、状态读取、参数修改  
  - 默认通信方式：**UCP 硬件保护模式（OmniCAN 串口 115200）**
  - 多机同步推荐：**Y42 聚合命令**
- **Embodied_SDK（上层）**：对“机械臂运动/视觉/手柄/IO/具身智能”等能力的统一封装  
  - 推荐入口：`HorizonArmSDK`
- **Main_UI（上位机）**：图形界面，不是二次开发必须依赖

---

## 2. `motors` 字典

大多数上层接口使用同一种“机械臂上下文”表示方式：

- **结构**：`{motor_id: controller_instance}`
- **motor_id**：电机地址（通常 1-6 对应 6 轴；夹爪若使用独立电机可能是 7）

示例：

```python
from Embodied_SDK import create_motor_controller

motors = {mid: create_motor_controller(motor_id=mid, port="COM14", baudrate=115200) for mid in range(1, 7)}
for m in motors.values():
    m.connect()
```

---

## 3. 电机角度 vs 关节输出角度

系统里会同时出现两种“角度”：

- **电机角度（motor angle）**：驱动器/电机端的角度，通常由 `motor.read_parameters.get_position()` 读到
- **关节输出角（joint angle）**：减速器输出端（关节）的角度，才是运动学计算更关心的值

二者的关系由 `config/motor_config.json` 决定：

- `motor_reducer_ratios`：减速比
- `motor_directions`：方向（1/-1）

很多上层逻辑会自动按该配置进行换算（例如 `MotionSDK`、`JoyconSDK`）。

---

## 4. 单位约定

- **关节角度**：度（deg）
- **末端位置**：毫米（mm），顺序 `[x, y, z]`
- **末端姿态**：度（deg），顺序 `[yaw, pitch, roll]`（在部分显示/打印中可能以 RPY 展示，请以函数参数说明为准）
- **电机速度**：RPM

---

## 5. 多电机同步

推荐同步方案是 **Y42 聚合多机命令**：

- 好处：一次通信下发多电机命令，硬件级同步启动，效率和稳定性更高
- 示例：`example/control_sdk_examples/multi_motor_sync_example.py`

旧方案“三阶段同步（multi_sync + sync_motion）”为兼容保留，不建议新项目依赖。

---

## 6. 安全与急停

- **停止（stop）**：停止运动，但保持使能（一般更安全）
- **失能（disable）**：断驱动电流，可能导致无刹车机械臂下坠（谨慎）
- **急停**：请优先使用物理急停/断电；软件急停仅作为辅助手段

推荐先阅读：[安全须知](safety.md)

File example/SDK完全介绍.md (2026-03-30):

# Embodied_SDK 完全介绍

## 📦 SDK 概述

**Embodied_SDK** 是 HorizonArm 机械臂的 Python 控制库，提供了从底层电机控制到高层AI功能的完整解决方案。

### 设计理念

```
高层应用
    ↑
具身智能层 (Embodied AI)
    ↑
功能模块层 (Motion, Vision, JoyCon, IO, DigitalTwin)
    ↑
电机控制层 (Motor Controller)
    ↑
通信协议层 (CAN/Serial)
```

---

## 🏗️ SDK 架构

### 核心模块总览

| 模块 | 文件 | 功能 | 适用场景 |
|---|---|---|---|
| **电机控制** | `__init__.py` | 单电机底层控制 | 所有应用的基础 |
| **运动控制** | `motion.py` | 多关节运动学 | 机械臂轨迹规划 |
| **视觉抓取** | `visual_grasp.py` | 手眼标定+抓取 | 视觉引导操作 |
| **手柄控制** | `joycon.py` | Joy-Con遥操作 | 远程操控 |
| **IO控制** | `io.py` | 数字IO读写 | 传感器/执行器接口 |
| **数字孪生（可选）** | `digital_twin.py` | MuJoCo仿真 | 算法验证/离线开发 |
| **AI集成** | `ai.py` | AI功能封装 | 大模型/多模态AI |
| **具身智能** | `embodied.py` | 完整AI机器人 | 端到端应用 |
| **集成SDK** | `horizon_sdk.py` | 高层统一接口 | 快速开发 |

---

## 📚 模块详解

### 1️⃣ 电机控制模块 (`__init__.py`)

**核心功能：单电机底层控制**

```python
from Embodied_SDK import create_motor_controller

# 创建电机控制器
motor = create_motor_controller(
    motor_id=1,
    port="COM14",
    baudrate=115200  # UCP硬件保护模式（OmniCAN 串口）
)

# 连接电机
motor.connect()

# 控制动作
motor.control_actions.enable()                    # 使能
motor.control_actions.set_speed(speed=100)        # 速度模式
motor.control_actions.move_to_position(90, 500)   # 位置模式
motor.control_actions.stop()                      # 停止

# 读取参数
position = motor.read_parameters.get_position()   # 读位置
speed = motor.read_parameters.get_speed()         # 读速度
status = motor.read_parameters.get_motor_status() # 读状态
```

**API分类：**

| API类别 | 方法 | 说明 |
|---|---|---|
| **连接管理** | `connect()`, `disconnect()` | 建立/断开连接 |
| **控制动作** | `control_actions.*` | 使能、运动、停止等 |
| **参数读取** | `read_parameters.*` | 位置、速度、状态等 |
| **参数设置** | `set_parameters.*` | PID、限位等配置 |
| **回零功能** | `homing_functions.*` | 各种回零模式 |

**详细示例：** `control_sdk_examples/motor_usage_example.py`

---

### 2️⃣ 运动控制模块 (`motion.py`)

**核心功能：多关节运动学和轨迹规划**

```python
from Embodied_SDK import HorizonArmSDK

# 创建机械臂SDK（自动管理6个电机）
sdk = HorizonArmSDK(motors={1: m1, 2: m2, ...})

# 关节空间运动
sdk.motion.move_joints([0, 45, 30, 0, 0, 0], duration=2.0)

# 笛卡尔空间运动
sdk.motion.move_cartesian([200, 100, 300], orientation=[0, 0, 180], duration=2.0)

# 预设动作
sdk.motion.execute_preset_action("初始位置")
sdk.motion.execute_preset_action("挥手")

# 夹爪控制
sdk.motion.control_claw(1)  # 张开
sdk.motion.control_claw(0)  # 闭合
```

**功能特性：**
- ✅ 关节空间运动（Joint Space）
- ✅ 笛卡尔空间运动（Cartesian Space）
- ✅ 逆运动学解算（IK）
- ✅ 轨迹插值（平滑运动）
- ✅ 预设动作管理
- ✅ 夹爪控制

**详细示例：** `sdk_quickstart.py`（完整版）

---

### 3️⃣ 视觉抓取模块 (`visual_grasp.py`)

**核心功能：手眼标定和视觉引导操作**

```python
from Embodied_SDK import HorizonArmSDK

sdk = HorizonArmSDK(motors=motors, camera_id=0)

# 像素点抓取（将屏幕像素转换为机械臂坐标）
sdk.vision.grasp_at_pixel(u=320, v=240)

# 框选抓取（抓取矩形框中心）
sdk.vision.grasp_at_bbox(x1=100, y1=100, x2=200, y2=200)

# 视觉跟随
sdk.follow.init_manual_target(frame, x1, y1, x2, y2)
sdk.follow.follow_step(frame)
```

**功能特性：**
- ✅ 手眼标定（Camera-Arm Calibration）
- ✅ 像素→机械臂坐标转换
- ✅ 深度估计（Depth Estimation）
- ✅ 目标跟踪（Object Tracking）
- ✅ 视觉伺服（Visual Servoing）

**前置条件：**
- 需要完成相机标定（生成 `config/calibration_parameter.json`）
- 摄像头已连接

**详细示例：** `control_sdk_examples/visual_grasp_example.py`

---

### 4️⃣ 手柄控制模块 (`joycon.py`)

**核心功能：Joy-Con手柄遥操作机械臂**

```python
from Embodied_SDK import JoyconSDK

sdk = JoyconSDK()

# 连接手柄
left_ok, right_ok = sdk.connect_joycon()

# 读取状态
left_status = sdk.get_left_joycon_status()
right_status = sdk.get_right_joycon_status()

# 绑定机械臂
sdk.bind_arm(motors)

# 启动控制循环
sdk.start_control()  # 手柄输入自动映射到机械臂运动

# 启用姿态模式（新功能）
sdk.set_attitude_mode("joint")   # 推荐：关节模式（原 Mode2）
sdk.enable_attitude()            # 启用姿态模式（默认 joint）

# 双臂姿态模式（新功能）
sdk.set_arm2(motors_arm2, motor_config_manager, kinematics)  # 绑定机械臂2
sdk.set_dual_attitude_enabled(True)  # 启用双臂姿态模式
```

**控制模式：**

1. **关节模式**：直接控制各关节角度
2. **笛卡尔模式**：控制末端在空间中的位置和姿态
3. **姿态模式**（新功能）：使用IMU控制末端姿态
   - **TCP模式（原 Mode1）**：IMU 控制末端姿态；右摇杆控制世界坐标系平移
   - **关节模式（原 Mode2，推荐）**：IMU 轴对轴映射到关节；右摇杆控制第一人称平移
4. **双臂姿态模式**（新功能）：同时控制两个机械臂

**基础模式控制映射：**

| 手柄 | 输入 | 笛卡尔模式 | 关节模式 |
|---|---|---|---|
| **左手柄** | 摇杆H | X轴移动 | J1旋转 |
| **左手柄** | 摇杆V | Y轴移动 | J2旋转 |
| **左手柄** | L/ZL | Z轴升降 | J3旋转 |
| **右手柄** | 摇杆H | Roll旋转 | J4旋转 |
| **右手柄** | 摇杆V | Pitch旋转 | J5旋转 |
| **右手柄** | R/ZR | Yaw旋转 | J6旋转 |
| **右手柄** | A | 夹爪闭合 | 夹爪闭合 |
| **右手柄** | B | 夹爪张开 | 夹爪张开 |
| **右手柄** | X | 切换模式 | 切换模式 |
| **右手柄** | HOME | 紧急停止 | 紧急停止 |

**姿态模式控制映射：**

| 手柄 | 输入 | 功能 |
|---|---|---|
| **右手柄** | IMU（陀螺仪） | 控制末端姿态（Roll/Pitch/Yaw） |
| **右手柄** | 摇杆 | 控制X/Y平移（世界坐标系） |
| **右手柄** | R/ZR | 控制Z轴升降（世界坐标系） |
| **右手柄** | X | 暂停/恢复IMU（摇杆平移仍可用） |
| **右手柄** | HOME | 短按=姿态对齐，长按=回安全位+对齐 |
| **右手柄** | A/B | 闭合/打开夹爪 |

**双臂姿态模式：**
- 右手柄控制机械臂1（Arm1）
- 左手柄控制机械臂2（Arm2）
- 左手柄方向键提供额外控制功能

**详细示例：** `control_sdk_examples/joycon_control_example.py`

---

### 5️⃣ IO控制模块 (`io.py`)

**核心功能：数字输入输出控制**

```python
from Embodied_SDK import IOSDK

io = IOSDK(port="COM15")
io.connect()

# 读取数字输入（DI）
di_states = io.read_di_states()  # 返回 {0: True, 1: False, ...}

# 控制数字输出（DO）
io.set_do(pin=0, state=True)   # 设置DO0为高电平
io.set_do(pin=1, state=False)  # 设置DO1为低电平

# 读取数字输出状态
do_states = io.read_do_states()
```

**应用场景：**
- 🔌 传感器信号读取（光电开关、接近开关、限位开关）
- 🔌 执行器控制（继电器、电磁阀、指示灯）
- 🔌 安全光栅联动
- 🔌 气动夹爪控制

**详细示例：** `control_sdk_examples/io_control_example.py`

---

### 6️⃣ 数字孪生模块 (`digital_twin.py`)

**核心功能：MuJoCo 物理仿真（可选）**

```python
from Embodied_SDK import DigitalTwinSDK

sdk = DigitalTwinSDK()

# 启动仿真窗口
sdk.start_simulation()

# 直接设置关节角度（瞬间）
sdk.set_joint_angles([0, 45, 30, 0, 0, 0])

# 平滑移动（带插值）
sdk.move_joints([90, 0, 0, 0, 0, 0], duration=2.0)

# 执行预设动作
sdk.execute_preset_action("初始位置")

# 停止仿真
sdk.stop_simulation()
```

**应用场景：**
- 🦾 算法验证（无需真实硬件）
- 🦾 轨迹预览（可视化运动路径）
- 🦾 离线开发（在家也能开发）
- 🦾 教学演示（安全展示）

**详细示例：**
- `control_sdk_examples/digital_twin_example.py`（教学版最短示例）
- `mujoco_control.py`（交互式完整演示）

---

### 7️⃣ AI集成模块 (`ai.py`)

**核心功能：AI功能封装（LLM、ASR、TTS、多模态）**

```python
from Embodied_SDK import AISDK

ai = AISDK()

# 大语言模型（LLM）
response = ai.llm.chat("请帮我规划一个抓取任务")

# 语音识别（ASR）
text = ai.asr.recognize(audio_data)

# 语音合成（TTS）
audio = ai.tts.synthesize("任务完成")

# 多模态理解
result = ai.multimodal.analyze(image, prompt="这是什么物体？")
```

**支持的AI能力：**
- 🧠 大语言模型（LLM）
- 🎤 语音识别（ASR）
- 🔊 语音合成（TTS）
- 👁️ 视觉理解（Vision）
- 🌐 多模态交互（Multimodal）

**详细示例：** `ai_sdk_examples/` 目录下的所有示例

---

### 8️⃣ 具身智能模块 (`embodied.py`)

**核心功能：端到端AI机器人系统**

```python
from Embodied_SDK import EmbodiedSDK

embodied = EmbodiedSDK()
result = embodied.run_nl_instruction("帮我把桌上的红色方块拿起来")
print(result)
```

**整合能力：**
- 🤖 自然语言理解 → 动作规划 → 执行
- 🤖 视觉感知 → AI决策 → 机械臂控制
- 🤖 语音交互 → 任务执行 → 反馈

---

### 9️⃣ 高层集成SDK (`horizon_sdk.py`)

**核心功能：统一接口，简化开发**

```python
from Embodied_SDK import HorizonArmSDK
from Embodied_SDK import create_motor_controller

# 一次性初始化所有功能（电机需要先由你连接并组成 motors 字典）
motors = {mid: create_motor_controller(motor_id=mid, port="COM14", baudrate=115200) for mid in range(1, 7)}
for m in motors.values():
    m.connect()

sdk = HorizonArmSDK(motors=motors, camera_id=0)

# 使用统一接口
sdk.vision.grasp_at_pixel(320, 240)  # 视觉抓取
sdk.motion.move_cartesian([100, 200, 300], orientation=[0, 0, 180])  # 运动控制
```

---

## 🔑 核心概念

### 1. 电机控制器 (Motor Controller)

每个电机对应一个控制器实例：
```python
motor = create_motor_controller(motor_id=1, port="COM14")
```

**关键参数：**
- `motor_id`: 电机ID（1-255），通过拨码开关或上位机设置
- `port`: 串口号（Windows: COMx, Linux: /dev/ttyUSBx）
- `baudrate`: 默认 115200（UCP硬件保护模式；一般不需要修改）
- `interface_type` / `shared_interface`: 旧SLCAN方案遗留参数，当前版本会自动忽略（不建议再使用）

### 2. 多电机连接（UCP 连接池共享）

UCP 模式下，多电机会自动共享同一串口连接（连接池机制），通常不需要额外的 `shared_interface` 配置：

```python
motors = {mid: create_motor_controller(motor_id=mid, port="COM14", baudrate=115200) for mid in range(1, 7)}
for m in motors.values():
    m.connect()
```

### 3. 多电机同步控制（推荐：Y42 聚合）

推荐使用 `ZDTMotorController.y42_sync_*` 进行同步控制（一次通信下发多电机命令，硬件级同步启动）：

```python
from Horizon_Core.Control_SDK.Control_Core import ZDTMotorController

controllers = {1: motor1, 2: motor2}
targets = {1: 90.0, 2: 45.0}  # 单位：度（电机角度）

ZDTMotorController.y42_sync_enable(controllers, enabled=True)
ZDTMotorController.y42_sync_position(controllers, targets=targets, speed=500)
```

### 4. 坐标系统

**关节空间（Joint Space）：**
- 直接控制每个关节的角度
- 参数：[J1, J2, J3, J4, J5, J6]（单位：度）
- 优点：直观、精确
- 缺点：需要手动计算姿态

**笛卡尔空间（Cartesian Space）：**
- 控制末端执行器的位置和姿态
- 参数：[X, Y, Z, Roll, Pitch, Yaw]（位置单位：mm，姿态单位：度）
- 优点：符合直觉（前后左右上下）
- 缺点：依赖逆运动学解算

### 5. 手眼标定 (Hand-Eye Calibration)

**原理：**
```
像素坐标 (u, v) → 相机坐标 → 机械臂基座标 → 关节角度
```

**标定过程：**
1. 采集标定数据（棋盘格）
2. 计算相机内参（camera_matrix, dist_coeffs）
3. 计算手眼关系（旋转向量rvec, 平移向量tvec）
4. 保存标定文件（`config/calibration_parameter.json`）

**使用：**
```python
sdk.vision.grasp_at_pixel(u=320, v=240)  # SDK自动加载标定文件
```

---

## 🎯 典型应用流程

### 场景1：简单的机械臂运动

```python
from Embodied_SDK import create_motor_controller
from Horizon_Core.Control_SDK.Control_Core import ZDTMotorController
import time

# 1. 创建控制器（默认：OmniCAN / UCP 115200）
motors = {}
for mid in [1, 2, 3, 4, 5, 6]:
    m = create_motor_controller(motor_id=mid, port="COM14", baudrate=115200)
    m.connect()
    motors[mid] = m

# 2. Y42 同步使能（推荐）
ZDTMotorController.y42_sync_enable(motors, enabled=True)
time.sleep(0.2)

# 3. Y42 聚合同步位置控制（推荐）
targets = {1: 0, 2: 45, 3: 30, 4: 0, 5: 0, 6: 0}
ZDTMotorController.y42_sync_position(motors, targets=targets, speed=500)

# 4. 等待到位
time.sleep(3)

# 5. 清理
for m in motors.values():
    m.disconnect()
```

### 场景2：视觉引导抓取

```python
from Embodied_SDK import HorizonArmSDK

# 1. 初始化SDK（自动连接电机和相机）
sdk = HorizonArmSDK(motors=motors, camera_id=0)

# 2. 移动到观察位置
sdk.motion.execute_preset_action("观察位置")

# 3. 获取图像
import cv2
cap = cv2.VideoCapture(0)
ret, frame = cap.read()

# 4. 用户点击目标（或AI识别）
# 假设用户点击了像素点(320, 240)
u, v = 320, 240

# 5. 执行视觉抓取
sdk.vision.grasp_at_pixel(u, v)

# 6. 移动到放置位置
sdk.motion.move_cartesian([200, 0, 200], orientation=[0, 0, 180])

# 7. 松开夹爪
sdk.motion.control_claw(1)  # 张开
```

### 场景3：AI交互式机器人

```python
from Embodied_SDK import HorizonArmSDK
from Embodied_SDK import AISDK

# 1. 初始化
arm = HorizonArmSDK(motors=motors, camera_id=0)
ai = AISDK()

# 2. 语音识别用户指令
audio = record_audio()  # 录音函数（需自己实现）
command = ai.asr.recognize(audio)
print(f"用户说: {command}")

# 3. LLM理解指令并生成动作序列
prompt = f"用户指令：{command}\n请分解为机械臂动作序列"
response = ai.llm.chat(prompt)
actions = parse_actions(response)  # 解析动作（需自己实现）

# 4. 执行动作
for action in actions:
    if action['type'] == 'move':
        arm.move_to_position(**action['params'])
    elif action['type'] == 'grasp':
        arm.claw.close()
    elif action['type'] == 'release':
        arm.claw.open()

# 5. 语音反馈
feedback_audio = ai.tts.synthesize("任务完成")
play_audio(feedback_audio)  # 播放函数（需自己实现）
```

---

## 📦 安装和配置

### 1. 安装依赖

```bash
# 基础依赖
pip install numpy opencv-python pyserial

# MuJoCo仿真（可选）
pip install mujoco

# Joy-Con控制（可选）
pip install joycon-python hidapi

# AI功能（可选）
pip install openai anthropic requests
```

### 2. 配置文件

**机械臂配置：**
- `config/embodied_config/preset_actions.json` - 预设动作定义
- `config/dh_parameters_config.json` - SDK 默认 FK/IK/DH 参数、`joint_offsets`、`joint_limits`
- `config/motor_config.json` - 电机减速比与方向配置

**AI配置：**
- `config/aisdk_config.yaml` - AI SDK 统一配置入口

**视觉配置：** `config/`
- `calibration_parameter.json` - 手眼标定参数

---

## 🔧 高级特性

### 1. 运动轨迹插值

SDK自动在关键点之间插值：
```python
# 以下会生成平滑轨迹
sdk.motion.move_joints([0, 0, 0, 0, 0, 0], duration=2.0)
sdk.motion.move_joints([90, 45, 30, 0, 0, 0], duration=2.0)
```

### 2. 碰撞检测（仿真中）

```python
sdk = DigitalTwinSDK()
sdk.enable_collision_detection(True)
```

### 3. 力控模式

```python
motor.control_actions.set_torque(current=500, current_slope=1000)
```

### 4. 自定义预设动作

编辑 `config/embodied_config/preset_actions.json`：
```json
{
  "我的动作": {
    "joints": [0, 45, 30, 0, 0, 0],
    "duration": 2.0,
    "description": "自定义动作描述"
  }
}
```

---

## 📖 学习资源

### 示例代码索引

| 学习目标 | 示例文件 | 难度 | 时间 |
|---|---|---|---|
| **快速入门** | `quickstart_guide.py` | ⭐ | 5分钟 |
| **单电机控制** | `control_sdk_examples/motor_usage_example.py` | ⭐⭐ | 30分钟 |
| **机械臂运动** | `sdk_quickstart.py` | ⭐⭐ | 30分钟 |
| **视觉抓取** | `control_sdk_examples/visual_grasp_example.py` | ⭐⭐⭐ | 45分钟 |
| **多机同步** | `control_sdk_examples/multi_motor_sync_example.py` | ⭐⭐⭐ | 20分钟 |
| **手柄控制** | `control_sdk_examples/joycon_control_example.py` | ⭐⭐⭐ | 40分钟 |
| **IO控制** | `control_sdk_examples/io_control_example.py` | ⭐⭐ | 20分钟 |
| **MuJoCo仿真** | `control_sdk_examples/digital_twin_example.py` | ⭐⭐ | 15分钟 |
| **AI功能** | `ai_sdk_examples/LLM_usage.py` | ⭐⭐⭐ | 30分钟 |

### 文档

- **总导航**: `example/README.md`
- **学习路径**: `example/control_sdk_examples/README.md`
- **API参考**: `docs/api_reference.md`
- **故障排除**: `docs/troubleshooting.md`

---

## ⚠️ 常见问题

### Q1: 电机连接失败？
**A:** 检查：
1. 串口号是否正确（设备管理器查看）
2. 电机ID是否正确
3. 电机是否上电
4. 没有其他程序占用串口

### Q2: 多电机控制失败？
**A:** 当前默认是 UCP 模式，多电机会自动共享同一串口连接（连接池）。建议按下面方式创建即可：
```python
motors = {mid: create_motor_controller(motor_id=mid, port="COM14", baudrate=115200) for mid in range(1, 7)}
for m in motors.values():
    m.connect()
```

### Q3: 视觉抓取位置不准？
**A:** 
1. 检查是否完成手眼标定
2. 确认标定文件路径正确
3. 检查相机和机械臂相对位置是否改变

### Q4: 仿真窗口无法打开？
**A:** 
```bash
pip install mujoco
```

### Q5: Joy-Con无法连接？
**A:** 
1. 在系统蓝牙设置中删除手柄
2. 按住手柄侧面同步按钮重新配对
3. 确保没有其他程序占用（Steam, Yuzu等）

---

## 🚀 从示例到生产

### 代码复用建议

1. **复制核心代码片段** - 示例代码可直接复制
2. **添加错误处理** - 生产环境加强异常处理
3. **添加日志记录** - 使用 `setup_logging()`
4. **参数配置化** - 将硬编码参数移到配置文件
5. **多线程处理** - 视觉/AI/控制分离线程

### 性能优化

- 🚀 使用共享接口减少串口开销
- 🚀 批量读取参数（多机同步场景）
- 🚀 异步处理耗时操作（AI推理）
- 🚀 预加载配置文件（避免重复读取）

---

## 📞 技术支持

- **示例代码**: `example/` 目录
- **开发者工具**: `example/developer_tools/`
- **技术文档**: `docs/`
- **问题反馈**: 联系技术支持团队

---

**版本**: 1.4  
**更新日期**: 2024  
**维护**: HorizonArm Team

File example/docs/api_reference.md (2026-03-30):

# API 参考（Embodied_SDK）

本页面按模块列出 `Embodied_SDK` 的主要入口、参数含义与常用用法，并附带对应示例脚本位置，方便快速对照。

## 快速入口

- **5分钟入门**：`example/quickstart_guide.py`
- **交互式完整示例**：`example/sdk_quickstart.py`
- **Joy-Con 控制**：`example/control_sdk_examples/joycon_control_example.py`、`example/test_joycon_arm_control.py`
- **仿真**：`example/mujoco_control.py`

## 1. 顶层入口：`HorizonArmSDK`

导入：`from Embodied_SDK import HorizonArmSDK`

构造参数：
- **motors**：`Dict[int, Any]`，电机控制器字典 `{motor_id: controller}`
- **camera_id**：`int`，摄像头编号（默认 0）

创建后可直接使用这些子模块：

| 属性 | 类型 | 常用用途 |
| :--- | :--- | :--- |
| `vision` | `VisualGraspSDK` | 点击/框选抓取 |
| `follow` | `FollowGraspSDK` | 视觉跟随/伺服 |
| `motion` | `MotionSDK` | 关节/末端运动、夹爪、预设动作 |
| `embodied` | `EmbodiedSDK` | 自然语言任务执行 |
| `io` | `IOSDK` | ESP32 IO 读写 |
| `digital_twin` | `DigitalTwinSDK` | MuJoCo 仿真控制 |
| `joycon` | `JoyconSDK` | Joy-Con 控制（可选） |

## 2. 运动控制：`MotionSDK`

入口：`sdk.motion`

常用接口：
- **`bind_motors(motors, use_motor_config=True, reducer_ratios=None, directions=None)`**：绑定电机上下文
- **`set_motion_params(max_speed=100, acceleration=50, deceleration=50)`**：设置运动参数
- **`move_joints(joint_angles, duration=None) -> bool`**：关节空间运动，`joint_angles` 为 6 个角度（度）
- **`move_cartesian(position, orientation=None, duration=None) -> bool`**：末端运动，`position=[x,y,z]`（mm），`orientation=[yaw,pitch,roll]`（度）
- **`execute_preset_action(name, speed="normal") -> bool`**：执行预设动作（参考 `config/embodied_config/preset_actions.json`）
- **`control_claw(action) -> bool`**：夹爪开合，`action=1` 张开，`action=0` 闭合
- **`get_claw_params()`**：读取夹爪参数（当前版本不再支持上位机设置夹爪角度/电流；`set_claw_params(...)` 为兼容保留但不会生效）

对应示例：`example/sdk_quickstart.py`

## 3. 视觉抓取：`VisualGraspSDK`

入口：`sdk.vision`

常用接口：
- **`bind_motors(motors, use_motor_config=True, reducer_ratios=None, directions=None)`**
- **`set_grasp_params(...)`**：设置抓取姿态、TCP 偏移、抓取深度等参数
- **`grasp_at_pixel(u, v) -> bool`**：抓取像素点（常用于点击）
- **`grasp_at_bbox(x1, y1, x2, y2) -> bool`**：抓取框中心点（常用于框选）

对应文档：`example/docs/vision.md`

## 4. 跟随抓取：`FollowGraspSDK`

入口：`sdk.follow`

常用接口：
- **`configure_follow(...)`**：配置跟随参数（目标类别、阈值、频率等）
- **`follow_step(frame) -> bool`**：单步跟随（推荐）
- **`start_follow_grasp(...)` / `stop_follow_grasp()` / `is_following()`**：后台循环跟随
- **`init_manual_target(frame0, x1, y1, x2, y2) -> bool`**：手动框选初始化跟踪器

## 5. Joy-Con：`JoyconSDK`

入口：`from Embodied_SDK import JoyconSDK`

常用接口：
- **`connect_joycon() -> (left_ok, right_ok)`**
- **`bind_arm(motors, use_motor_config=True, kinematics=None, mujoco_controller=None)`**
- **`start_control()` / `stop_control()` / `pause_control()` / `resume_control()`**
- **`toggle_mode()`**：切换关节/笛卡尔模式
- **`emergency_stop()`**：急停
- **`get_status() -> dict`**：读取控制状态
- **`get_left_joycon_status()` / `get_right_joycon_status()`**：读取手柄原始状态（用于终端监控）

对应示例：
- `example/control_sdk_examples/joycon_control_example.py`
- `example/test_joycon_display.py`

## 6. IO：`IOSDK`

入口：`from Embodied_SDK import IOSDK`

常用接口：
- **`connect() -> bool` / `disconnect()`**
- **`read_di(pin)` / `read_di_states()`**
- **`set_do(pin, state)` / `set_do_all(states)`**
- **`read_do_states()` / `reset_all_do()` / `pulse_do(pin, duration=0.1)`**
- **`get_version()` / `get_status()`**

## 7. 自然语言：`EmbodiedSDK`

入口：`from Embodied_SDK import EmbodiedSDK`

常用接口：
- **`run_nl_instruction(instruction) -> dict`**
- **`run_nl_instruction_stream(instruction, action_handler=None, progress_handler=None, completion_handler=None)`**
- **`get_available_functions() -> Dict[str, str]`**
- **`clear_history()` / `get_history()`**

## 8. 仿真：`DigitalTwinSDK`

入口：`from Embodied_SDK import DigitalTwinSDK`

常用接口：
- **`start_simulation() -> bool` / `stop_simulation()` / `is_running() -> bool`**
- **`set_joint_angles(angles) -> bool`**：直接设置关节角（用于同步/波形）
- **`move_joints(joint_angles, duration=None) -> bool`**
- **`move_cartesian(position, orientation=None, duration=None) -> bool`**
- **`execute_preset_action(name, speed="normal") -> bool`**
- **`clear_trajectory() -> bool`**

对应示例：`example/mujoco_control.py`

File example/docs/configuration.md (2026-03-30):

# 配置说明

本项目的配置默认位于项目根目录 `config/`。大多数脚本在“源码运行”模式下会自动优先读取该目录，无需额外设置。

---

## 1. 配置目录选择规则

许多模块（如 `Embodied_SDK/motion.py`、`Embodied_SDK/joycon.py`）会根据运行方式选择配置目录：

- **源码运行（未打包）**：默认使用项目内 `./config/`
- **打包运行（`sys.frozen=True`）**：优先使用环境变量
  - `HORIZONARM_CONFIG_DIR`：外置配置目录（推荐）
  - `HORIZON_DATA_DIR`：若设置，会尝试使用 `${HORIZON_DATA_DIR}/config`

如果你在自己的项目中复用 SDK，推荐显式设置：

```python
import os
os.environ["HORIZONARM_CONFIG_DIR"] = r"D:\HorizonArm\config"
```

---

## 2. 核心配置文件一览（`config/`）

### 2.1 `motor_config.json`（必读）

用于把“电机侧角度”换算到“关节输出端角度”，并统一方向约定。主要字段：

- `motor_reducer_ratios`: `{ "1": 50.0, ... }`  
  - **减速比**（电机角度 / 关节角度）
- `motor_directions`: `{ "1": -1, ... }`  
  - **方向**（1 或 -1），用于统一正方向
- `motor_directions_arm2`（可选）：
  - 双臂/副臂方向修正（仅在相关逻辑使用时生效）

影响模块：
- `MotionSDK` / `JoyconSDK`：运动学、单轴增量控制、姿态模式映射等
- 示例：`example/sdk_quickstart.py`

---

### 2.2 `calibration_parameter.json`（视觉相关）

相机标定与手眼标定参数。影响模块：
- `VisualGraspSDK` / `FollowGraspSDK`
- 示例：`example/control_sdk_examples/visual_grasp_example.py`

---

### 2.3 `hand_eye_calibration_poses.yaml`（标定采集位姿）

用于标定采集流程中的预设位姿/动作序列（具体由标定相关模块读取）。

---

### 2.4 `embodied_config/preset_actions.json`（预设动作）

预设动作字典（key 为动作名称），用于：
- `MotionSDK.execute_preset_action(name, speed=...)`
- `DigitalTwinSDK.execute_preset_action(name, speed=...)`
- 示例：`example/sdk_quickstart.py`

---

### 2.5 `aisdk_config.yaml`（AI 相关）

AI 提供商与模型的配置入口（建议使用环境变量注入密钥，避免提交到仓库）：

- Windows PowerShell：`setx ALI_API_KEY "your_key"`
- Linux/macOS：`export ALI_API_KEY=your_key`

影响模块：
- `Horizon_Core/AI_SDK`
- 示例：`example/ai_sdk_examples/config_example.py`

---

### 2.6 其他配置（按需）

- `all_parameter_config.json`：UI/系统级参数集合（上位机相关）
- `dh_parameters_config.json`：SDK 默认 FK/IK/DH 参数、`joint_offsets`、`joint_limits` 的统一配置
- `io_control/`：IO 作业/映射配置（`IOSDK` / UI IO 控件）
- `teaching_program/`：示教程序相关配置与样例

---

## 3. 常见问题

### Q1：我修改了 `config/`，为什么脚本没生效？

优先排查：
- 是否在脚本里设置了 `HORIZONARM_CONFIG_DIR` 指向了另一个目录
- 是否是打包运行（`sys.frozen=True`）导致读取外置配置

### Q2：方向反了/角度不对怎么办？

优先检查 `config/motor_config.json`：
- 方向反：修改对应电机的 `motor_directions` 为 `1` 或 `-1`
- 比例不对：修改对应电机的 `motor_reducer_ratios`

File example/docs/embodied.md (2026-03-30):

# EmbodiedSDK - 具身智能（自然语言控制）

**对应源码：** `Embodied_SDK/embodied.py`

## 概述

`EmbodiedSDK` 提供自然语言控制机械臂的能力，通过 AI 大模型理解用户指令并转换为机械臂动作。

## 前置条件

- 已配置 AI API 密钥（`config/aisdk_config.yaml`）
- 网络连接正常
- 已安装 `Horizon_Core.AI_SDK`

---

## 模块入口

### 通过顶层 SDK

```python
from Embodied_SDK import HorizonArmSDK

sdk = HorizonArmSDK(motors=motors)
embodied = sdk.embodied  # 获取 EmbodiedSDK 实例
```

### 独立使用

```python
from Embodied_SDK import EmbodiedSDK

embodied = EmbodiedSDK(
    provider="alibaba",      # AI 服务商：alibaba/deepseek
    model="qwen-turbo",      # 模型名称
    control_mode="both"      # 控制模式：real/simulation/both
)
```

---

## 核心接口

### 1. 执行自然语言指令

#### `run_nl_instruction(instruction) -> dict`

执行单条自然语言指令。

**参数：**
- `instruction`: 自然语言指令（字符串）

**返回值：**
- `dict`: 包含执行结果的字典
  - `success`: 是否成功
  - `action`: 执行的动作
  - `result`: 执行结果详情

**示例：**
```python
# 基础运动指令
result = embodied.run_nl_instruction("机械臂回到初始位置")
print(f"执行结果: {result['success']}")

# 关节控制指令
result = embodied.run_nl_instruction("将第一个关节转动30度")

# 末端运动指令
result = embodied.run_nl_instruction("移动到坐标(300, 200, 400)")

# 抓取指令
result = embodied.run_nl_instruction("抓取红色的物体")

# 复杂指令
result = embodied.run_nl_instruction("先回到初始位置，然后执行挥手动作")
```

---

### 2. 流式执行（带回调）

#### `run_nl_instruction_stream(instruction, action_handler=None, progress_handler=None, completion_handler=None)`

流式执行自然语言指令，支持实时反馈。

**参数：**
- `instruction`: 自然语言指令
- `action_handler`: 动作开始回调函数
- `progress_handler`: 进度更新回调函数
- `completion_handler`: 完成回调函数

**示例：**
```python
def on_action(action_name):
    print(f"开始执行动作: {action_name}")

def on_progress(progress):
    print(f"进度: {progress}%")

def on_completion(result):
    print(f"完成: {result}")

embodied.run_nl_instruction_stream(
    "机械臂做一个挥手动作",
    action_handler=on_action,
    progress_handler=on_progress,
    completion_handler=on_completion
)
```

---

### 3. 查询可用功能

#### `get_available_functions() -> Dict[str, str]`

获取系统支持的所有功能列表。

**返回值：**
- `dict`: 功能名称 → 功能描述

**示例：**
```python
functions = embodied.get_available_functions()
print("系统支持的功能：")
for name, desc in functions.items():
    print(f"  - {name}: {desc}")
```

---

### 4. 对话历史管理

#### `get_history() -> list`

获取对话历史记录。

```python
history = embodied.get_history()
for entry in history:
    print(f"用户: {entry['user']}")
    print(f"助手: {entry['assistant']}")
```

#### `clear_history()`

清空对话历史。

```python
embodied.clear_history()
```

---

## 完整示例

### 基础自然语言控制

```python
from Embodied_SDK import HorizonArmSDK, create_motor_controller

# 1. 连接电机
motors = {mid: create_motor_controller(motor_id=mid, port="COM14") for mid in range(1, 7)}
for m in motors.values():
    m.connect()

# 2. 初始化 SDK
sdk = HorizonArmSDK(motors=motors)

# 3. 初始化具身智能 SDK
embodied = sdk.embodied

# 4. 执行自然语言指令
instructions = [
    "机械臂回到初始位置",
    "将第一个关节转动30度",
    "移动到坐标(300, 200, 400)",
    "执行一个挥手动作"
]

for instruction in instructions:
    print(f"\n执行指令: {instruction}")
    result = embodied.run_nl_instruction(instruction)
    
    if result['success']:
        print(f"✅ 执行成功")
    else:
        print(f"❌ 执行失败: {result.get('error')}")

# 5. 清理
for m in motors.values():
    m.disconnect()
```

---

### 交互式对话控制

```python
from Embodied_SDK import EmbodiedSDK

# 初始化
embodied = EmbodiedSDK(provider="alibaba", model="qwen-turbo")

print("具身智能交互式控制")
print("输入自然语言指令，输入 'quit' 退出")
print("=" * 50)

while True:
    # 获取用户输入
    instruction = input("\n您的指令: ").strip()
    
    if instruction.lower() in ['quit', 'exit', 'q']:
        break
    
    if not instruction:
        continue
    
    # 执行指令
    try:
        result = embodied.run_nl_instruction(instruction)
        
        if result['success']:
            print(f"✅ 已执行: {result.get('action', '未知动作')}")
        else:
            print(f"❌ 执行失败: {result.get('error', '未知错误')}")
            
    except Exception as e:
        print(f"❌ 发生错误: {e}")

print("\n再见！")
```

---

### 先在仿真中测试（推荐）

```python
from Embodied_SDK import HorizonArmSDK

# 1. 初始化（不连接真实电机）
sdk = HorizonArmSDK(motors={})

# 2. 启动仿真
sdk.digital_twin.start_simulation()

# 3. 配置具身智能使用仿真模式
embodied = sdk.embodied

# 4. 在仿真中测试指令
test_instructions = [
    "机械臂向上移动100mm",
    "旋转第二个关节45度",
    "执行挥手动作"
]

print("在仿真中测试指令...")
for instruction in test_instructions:
    print(f"\n测试: {instruction}")
    result = embodied.run_nl_instruction(instruction)
    print(f"结果: {'成功' if result['success'] else '失败'}")

# 5. 观察仿真结果，确认无误后再连接真实机械臂
```

---

## 支持的指令类型

### 1. 运动控制
- "回到初始位置"
- "移动到坐标(x, y, z)"
- "向前移动50mm"
- "向上移动100mm"

### 2. 关节控制
- "第一个关节转动30度"
- "第二个关节转到45度"
- "所有关节归零"

### 3. 预设动作
- "执行挥手动作"
- "执行抓取准备姿态"
- "进入收纳姿态"

### 4. 夹爪控制
- "张开夹爪"
- "闭合夹爪"
- "抓取"

### 5. 视觉任务（如已连接相机）
- "抓取红色的物体"
- "跟随移动的目标"

---

## 配置文件

### aisdk_config.yaml

AI SDK 配置文件（`config/aisdk_config.yaml`）：

```yaml
providers:
  alibaba:
    api_key: ${ALI_API_KEY}
    default_params:
      max_tokens: 2000
      temperature: 0.7
    enabled: true
    
  deepseek:
    api_key: ${DEEPSEEK_API_KEY}
    default_params:
      max_tokens: 2000
      temperature: 0.7
    enabled: true
```

**设置 API 密钥：**

```bash
# Linux/Mac
export ALI_API_KEY="your_api_key"

# Windows
set ALI_API_KEY=your_api_key
```

---

## 注意事项

### 安全建议

1. **先仿真测试**：
   - 自然语言指令存在不确定性
   - 建议先在仿真中测试，确认无误后再用于真实机械臂

2. **指令明确性**：
   - 使用清晰、明确的指令
   - 避免模糊或复杂的描述

3. **监控执行**：
   - 执行过程中保持监控
   - 准备好急停措施

### 限制说明

- 依赖 AI 大模型，需要网络连接
- 复杂指令可能理解不准确
- 不适用于高精度、安全关键的任务

---

## 相关文档

- [MotionSDK](motion.md) - 运动控制接口
- [DigitalTwinSDK](simulation.md) - 仿真测试
- [安全须知](safety.md) - 安全操作指南
- [配置说明](configuration.md) - AI API 配置

## 示例脚本

- `example/ai_sdk_examples/smart_chat_example.py` - 智能对话示例
- `example/ai_sdk_examples/smart_multimodal_chat_demo.py` - 多模态对话示例

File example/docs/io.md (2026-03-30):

# IOSDK - IO 控制

**对应源码：** `Embodied_SDK/io.py`

## 概述

`IOSDK` 提供 ESP32 IO 控制能力，支持数字输入/输出（DI/DO）的读写操作。

## 前置条件

- ESP32 IO 控制器已连接
- 已烧录对应固件
- 串口连接正常

---

## 模块入口

### 通过顶层 SDK

```python
from Embodied_SDK import HorizonArmSDK

sdk = HorizonArmSDK(motors=motors)
io = sdk.io  # 获取 IOSDK 实例
```

### 独立使用

```python
from Embodied_SDK import IOSDK

io = IOSDK(port="COM15", baudrate=115200)
```

---

## 核心接口

### 1. 连接管理

#### `connect() -> bool`

连接 IO 控制器。

**返回值：**
- `True`: 连接成功
- `False`: 连接失败

**示例：**
```python
if io.connect():
    print("✅ IO 控制器已连接")
else:
    print("❌ 连接失败")
```

#### `disconnect()`

断开连接。

```python
io.disconnect()
```

---

### 2. 数字输入（DI）

#### `read_di(pin) -> bool`

读取单个数字输入引脚状态。

**参数：**
- `pin`: 引脚编号（通常 0-7）

**返回值：**
- `True`: 高电平
- `False`: 低电平

**示例：**
```python
state = io.read_di(0)
print(f"DI0 状态: {'HIGH' if state else 'LOW'}")
```

#### `read_di_states() -> dict`

读取所有数字输入引脚状态。

**返回值：**
- `dict`: `{pin: state}` 字典

**示例：**
```python
states = io.read_di_states()
print("所有 DI 状态:")
for pin, state in states.items():
    print(f"  DI{pin}: {'HIGH' if state else 'LOW'}")
```

---

### 3. 数字输出（DO）

#### `set_do(pin, state) -> bool`

设置单个数字输出引脚状态。

**参数：**
- `pin`: 引脚编号
- `state`: 状态（`True`/`1` = 高电平，`False`/`0` = 低电平）

**返回值：**
- `True`: 设置成功
- `False`: 设置失败

**示例：**
```python
# 设置 DO0 为高电平
io.set_do(0, True)

# 设置 DO1 为低电平
io.set_do(1, False)
```

#### `set_do_all(states) -> bool`

批量设置所有数字输出引脚。

**参数：**
- `states`: 状态字典 `{pin: state}` 或状态列表

**示例：**
```python
# 使用字典
io.set_do_all({0: True, 1: False, 2: True})

# 使用列表（按引脚顺序）
io.set_do_all([True, False, True, False, True, False, True, False])
```

---

### 4. 状态查询

#### `read_do_states() -> dict`

读取所有数字输出引脚的当前状态。

**返回值：**
- `dict`: `{pin: state}` 字典

**示例：**
```python
states = io.read_do_states()
print("所有 DO 状态:")
for pin, state in states.items():
    print(f"  DO{pin}: {'HIGH' if state else 'LOW'}")
```

---

### 5. 辅助功能

#### `reset_all_do()`

重置所有数字输出为低电平。

```python
io.reset_all_do()
print("所有 DO 已重置")
```

#### `pulse_do(pin, duration=0.1) -> bool`

在指定引脚上产生脉冲信号。

**参数：**
- `pin`: 引脚编号
- `duration`: 脉冲持续时间（秒）

**使用场景：**
- 触发继电器
- 发送触发信号

**示例：**
```python
# 在 DO0 上产生 100ms 的脉冲
io.pulse_do(0, duration=0.1)
```

---

### 6. 设备信息

#### `get_version() -> str`

获取 IO 控制器固件版本。

```python
version = io.get_version()
print(f"固件版本: {version}")
```

#### `get_status() -> dict`

获取设备状态信息。

**返回值：**
- `dict`: 包含连接状态、引脚状态等信息

**示例：**
```python
status = io.get_status()
print(f"连接状态: {status['connected']}")
print(f"DI 数量: {status['di_count']}")
print(f"DO 数量: {status['do_count']}")
```

---

## 完整示例

### 基础 IO 操作

```python
from Embodied_SDK import IOSDK
import time

# 1. 创建 IOSDK 实例
io = IOSDK(port="COM15", baudrate=115200)

# 2. 连接设备
if not io.connect():
    print("连接失败")
    exit(1)

print("✅ IO 控制器已连接")

# 3. 读取数字输入
print("\n读取数字输入:")
di_states = io.read_di_states()
for pin, state in di_states.items():
    print(f"  DI{pin}: {'HIGH' if state else 'LOW'}")

# 4. 控制数字输出
print("\n控制数字输出:")
io.set_do(0, True)   # DO0 高电平
print("  DO0: HIGH")
time.sleep(1)

io.set_do(0, False)  # DO0 低电平
print("  DO0: LOW")

# 5. 批量设置
print("\n批量设置 DO:")
io.set_do_all({0: True, 1: True, 2: False, 3: False})
print("  DO0-1: HIGH, DO2-3: LOW")
time.sleep(1)

# 6. 重置所有 DO
print("\n重置所有 DO")
io.reset_all_do()

# 7. 断开连接
io.disconnect()
print("\n✅ 已断开连接")
```

---

### 循环监控输入

```python
from Embodied_SDK import IOSDK
import time

io = IOSDK(port="COM15")
if not io.connect():
    exit(1)

print("开始监控数字输入，按 Ctrl+C 退出")

try:
    while True:
        # 读取所有输入
        states = io.read_di_states()
        
        # 检测 DI0 变化
        if states.get(0):
            print("⚠️  DI0 触发！")
            # 执行相应操作
            io.set_do(0, True)  # 点亮指示灯
            time.sleep(0.5)
            io.set_do(0, False)
        
        time.sleep(0.1)  # 10Hz 轮询
        
except KeyboardInterrupt:
    print("\n停止监控")
    
io.disconnect()
```

---

### 与机械臂联动

```python
from Embodied_SDK import HorizonArmSDK, create_motor_controller
import time

# 1. 初始化机械臂和 IO
motors = {mid: create_motor_controller(motor_id=mid, port="COM14") for mid in range(1, 7)}
for m in motors.values():
    m.connect()

sdk = HorizonArmSDK(motors=motors)
io = sdk.io
io.connect()

print("机械臂 + IO 联动控制")
print("DI0: 触发回到初始位置")
print("DI1: 触发抓取动作")

try:
    while True:
        # 读取输入
        di_states = io.read_di_states()
        
        # DI0 触发 - 回到初始位置
        if di_states.get(0):
            print("触发: 回到初始位置")
            sdk.motion.move_joints([0, 0, 0, 0, 0, 0])
            io.set_do(0, True)  # 指示灯
            time.sleep(0.5)
            io.set_do(0, False)
        
        # DI1 触发 - 抓取
        if di_states.get(1):
            print("触发: 抓取动作")
            sdk.motion.execute_preset_action("pick")
            io.set_do(1, True)  # 指示灯
            time.sleep(0.5)
            io.set_do(1, False)
        
        time.sleep(0.1)
        
except KeyboardInterrupt:
    print("\n停止")

# 清理
io.disconnect()
for m in motors.values():
    m.disconnect()
```

---

## 引脚说明

### 数字输入（DI）

通常 DI0-DI7，8 个输入引脚。

**典型用途：**
- 传感器信号检测
- 按钮输入
- 限位开关
- 外部触发信号

### 数字输出（DO）

通常 DO0-DO7，8 个输出引脚。

**典型用途：**
- 控制继电器
- 指示灯
- 外部设备触发
- 信号输出

---

## 配置文件

### IO 映射配置

可在 `config/io_control/io_mapping.json` 中定义引脚映射：

```json
{
  "inputs": {
    "emergency_stop": 0,
    "start_button": 1,
    "sensor_1": 2
  },
  "outputs": {
    "indicator_green": 0,
    "indicator_red": 1,
    "relay_1": 2
  }
}
```

---

## 注意事项

1. **电气安全**：
   - 确认电压电平匹配
   - 使用继电器隔离高压设备

2. **响应时间**：
   - 串口通信有延迟
   - 不适用于实时性要求极高的场景

3. **引脚保护**：
   - 避免短路
   - 使用合适的电流限制

---

## 相关文档

- [MotionSDK](motion.md) - 与机械臂联动
- [配置说明](configuration.md) - IO 映射配置
- [API 详细参考](api_detailed.md) - 完整 API 说明

## 示例脚本

- **`example/test_io.py`**  
  **用途：** IO 控制综合测试工具。  
  **功能：** 提供交互式菜单，支持读取所有 DI 状态、控制 DO 引脚以及实时监控模式。

- `config/io_control/` - IO 配置示例

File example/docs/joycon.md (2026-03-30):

# JoyconSDK - 手柄控制

**对应源码：** `Embodied_SDK/joycon.py`

## 概述

`JoyconSDK` 提供 Nintendo Joy-Con 手柄控制机械臂的能力，支持多种控制模式：
- **关节模式**：直接控制各关节角度
- **笛卡尔模式**：控制末端在空间中的位置和姿态
- **姿态模式**：使用IMU控制末端姿态（新功能）
  - **关节模式**（推荐，原 Mode2）
  - **TCP模式**（兼容，原 Mode1）
- **双臂姿态模式**：同时控制两个机械臂（新功能）

## 模块入口

```python
from Embodied_SDK import JoyconSDK

joycon = JoyconSDK()
```

---

## 使用流程

### 1. 连接手柄

#### `connect_joycon() -> (bool, bool)`

连接 Joy-Con 手柄。

**返回值：**
- `(left_ok, right_ok)`: 左右手柄连接状态

**示例：**
```python
left_ok, right_ok = joycon.connect_joycon()

if left_ok and right_ok:
    print("✅ 手柄连接成功")
else:
    print("❌ 手柄连接失败")
```

---

### 2. 绑定机械臂

#### `bind_arm(motors, use_motor_config=True, kinematics=None, mujoco_controller=None)`

绑定机械臂电机。

**参数：**
- `motors`: 电机字典 `{motor_id: controller}`
- `use_motor_config`: 是否从配置文件加载参数
- `kinematics`: 运动学对象（可选；不传时默认按 `config/dh_parameters_config.json` 创建）
- `mujoco_controller`: MuJoCo 控制器（可选，用于仿真）

**示例：**
```python
from Horizon_Core import gateway as horizon_gateway

motors = {mid: horizon_gateway.create_motor_controller(motor_id=mid, port="COM14") for mid in range(1, 7)}
for m in motors.values():
    m.connect()

joycon.bind_arm(motors, use_motor_config=True)
```

---

### 3. 启动控制

#### `start_control()`

启动手柄控制循环。

**示例：**
```python
joycon.start_control()
print("手柄控制已启动，按 Joy-Con 按钮控制机械臂")
print("按 Ctrl+C 退出")

try:
    while True:
        time.sleep(0.1)
except KeyboardInterrupt:
    joycon.stop_control()
```

---

## 控制方法

### 停止/暂停/恢复

```python
# 停止控制
joycon.stop_control()

# 暂停控制
joycon.pause_control()

# 恢复控制
joycon.resume_control()
```

### 模式切换

#### `toggle_mode()`

在关节模式和笛卡尔模式之间切换。

```python
joycon.toggle_mode()
```

**说明：**
- **关节模式**：直接控制各关节角度
- **笛卡尔模式**：控制末端在空间中的位置和姿态

#### `enable_attitude(mode="joint") -> bool`

启用姿态模式（使用右手柄IMU控制末端姿态）。

```python
success = joycon.enable_attitude()  # 默认 joint
if success:
    print("姿态模式已启用")
```

**说明：**
- 姿态模式有两种“子模式”：TCP模式 / 关节模式（推荐）
- 两种子模式都支持：X 暂停/恢复 IMU（平移仍可用），HOME 短按对齐/长按回安全位+对齐

#### `disable_attitude_mode()`

禁用姿态模式，回到基础控制模式。

```python
joycon.disable_attitude_mode()
```

#### `set_attitude_mode(mode)`

选择姿态模式子模式（建议在启用姿态模式前设置）。

```python
# 关节模式（推荐，原 Mode2）
joycon.set_attitude_mode("joint")

# TCP模式（兼容，原 Mode1）
joycon.set_attitude_mode("tcp")
```

**说明：**
- **TCP模式（原 Mode1）**：
  - IMU：控制末端姿态（Yaw/Pitch/Roll）
  - 右摇杆：X/Y 平移（世界坐标系）
  - R/ZR：Z 轴升降（世界坐标系）
- **关节模式（原 Mode2，推荐）**：
  - IMU：轴对轴映射到关节（Yaw→J1，Pitch→J5，Roll→J6）
  - 右摇杆：第一人称平移（沿末端前向/右向，需 IK）
  - R/ZR：Z 轴升降（世界坐标系）

**方向/映射符号调整（常用排查项）：**
- TCP模式左右手柄镜像翻转：`attitude_left_flip_roll` / `attitude_left_flip_pitch` / `attitude_left_flip_yaw`
- 关节模式映射符号（右/左手柄）：`attitude_mode2_yaw_sign_right/left`、`attitude_mode2_pitch_sign_right/left`、`attitude_mode2_roll_sign_right/left`
- 若双臂需要单独微调 arm2：`attitude_mode2_arm2_yaw_sign_mult/pitch_sign_mult/roll_sign_mult`

> 兼容说明：旧接口 `set_attitude_mode2_enabled(True/False)` 仍保留，但推荐使用 `set_attitude_mode(...)`。

#### `set_dual_attitude_enabled(enabled: bool)`

设置双臂姿态模式开关（仅在姿态模式下生效）。

```python
# 启用双臂姿态模式
joycon.set_dual_attitude_enabled(True)

# 禁用双臂姿态模式
joycon.set_dual_attitude_enabled(False)
```

**说明：**
- 双臂姿态模式需要同时连接左右Joy-Con
- 右手柄控制机械臂1（Arm1）
- 左手柄控制机械臂2（Arm2）
- 需要先通过 `set_arm2()` 绑定机械臂2

#### `set_arm2(motors, motor_config_manager=None, kinematics=None, mujoco_controller=None, arm_index=2)`

绑定机械臂2（用于双臂姿态模式）。

```python
# 连接机械臂2的电机
from Horizon_Core import gateway as horizon_gateway

motors_arm2 = {mid: horizon_gateway.create_motor_controller(motor_id=mid, port="COM15") for mid in range(1, 7)}
for m in motors_arm2.values():
    m.connect()

# 绑定机械臂2
joycon.set_arm2(motors_arm2, motor_config_manager, kinematics)
```

#### `move_to_joycon_start_pose(force=False) -> bool`

移动到手柄控制的起始位姿（安全位姿）。

```python
success = joycon.move_to_joycon_start_pose()
if success:
    print("已移动到起始位姿")
```

---

### 紧急停止

#### `emergency_stop()`

触发紧急停止。

```python
joycon.emergency_stop()
```

---

## 状态查询

### 获取控制状态

#### `get_status() -> dict`

获取当前控制状态。

```python
status = joycon.get_status()
print(f"模式: {status['mode']}")
print(f"速度倍率: {status['speed_multiplier']}")
print(f"是否运行: {status['running']}")
```

---

### 获取手柄状态

#### `get_left_joycon_status()` / `get_right_joycon_status()`

获取手柄原始状态（用于监控）。

```python
left_status = joycon.get_left_joycon_status()
right_status = joycon.get_right_joycon_status()

if left_status:
    print(f"左摇杆: {left_status.get('stick_l')}")
if right_status:
    print(f"右摇杆: {right_status.get('stick_r')}")
```

---

## 完整示例

请参考 `example/test_joycon_arm_control.py`，该文件展示了如何构建一个全功能的交互式控制台：

1.  **交互式配置**：启动时询问串口号和电机 ID。
2.  **安全检查**：显示详细的控制键位说明。
3.  **主控制循环**：
    *   实时读取手柄状态
    *   根据模式计算目标位姿
    *   调用 SDK 执行运动
    *   刷新屏幕显示状态

```python
# 代码片段：主控制逻辑示意
def main():
    # ... (连接电机与手柄) ...
    
    joycon.bind_arm(motors, use_motor_config=True)
    joycon.start_control()
    
    try:
        while True:
            # 刷新状态显示
            status = joycon.get_status()
            print_status(status, motors)
            time.sleep(0.1)
    except KeyboardInterrupt:
        joycon.stop_control()
```

---

## 按键映射

### 基础模式（关节/笛卡尔）

#### 左 Joy-Con
- **摇杆**：XY平面移动（笛卡尔）/ J1-J2转动（关节）
- **L/ZL**：Z轴升降（笛卡尔）/ J3转动（关节）
- **减号(-)**：降低速度

#### 右 Joy-Con
- **摇杆**：俯仰/翻滚（笛卡尔）/ J4-J5转动（关节）
- **R/ZR**：偏航旋转（笛卡尔）/ J6转动（关节）
- **X 键**：切换关节/笛卡尔模式
- **A 键**：闭合夹爪
- **B 键**：打开夹爪
- **加号(+)**：提高速度
- **HOME**：紧急停止

### 姿态模式（ATTITUDE）

#### 右 Joy-Con（单臂模式）
- **IMU（陀螺仪）**：控制末端姿态（Roll/Pitch/Yaw）
- **摇杆**：控制X/Y平移（世界坐标系）
- **R/ZR**：控制Z轴升降（世界坐标系）
- **X 键**：暂停/恢复IMU（摇杆平移仍可用）
- **HOME**：短按=姿态对齐，长按=回安全位+对齐
- **A 键**：闭合夹爪
- **B 键**：打开夹爪

#### 左 Joy-Con（双臂模式）
- **IMU（陀螺仪）**：控制机械臂2末端姿态
- **摇杆**：控制机械臂2的X/Y平移
- **L/ZL**：控制机械臂2的Z轴升降
- **方向键左(←)**：暂停/恢复IMU
- **方向键上(↑)**：回零
- **方向键右(→)**：闭合夹爪
- **方向键下(↓)**：打开夹爪

---

## 注意事项

1. **手柄连接**：
   - 确保 Joy-Con 已通过蓝牙配对
   - Windows 系统需要安装对应驱动

2. **控制模式**：
   - 关节模式更直观，适合新手
   - 笛卡尔模式更灵活，需要熟练使用
   - 姿态模式使用IMU控制，提供更直观的操作体验

3. **速度调节**：
   - 可通过手柄按键调节速度倍率
   - 首次使用建议使用低速模式

4. **姿态模式**：
   - 首次使用建议先进行姿态对齐（按HOME键）
   - 可以随时按X键暂停IMU控制
   - 关节模式（原 Mode2）提供更直观的“IMU→关节”手感与第一人称平移

5. **双臂姿态模式**：
   - 需要同时连接左右Joy-Con
   - 需要先通过 `set_arm2()` 绑定机械臂2
   - 右手柄控制Arm1，左手柄控制Arm2

---

## 相关文档

- [MotionSDK](motion.md) - 运动控制接口
- [安全须知](safety.md) - 安全操作指南
- [API 详细参考](api_detailed.md) - 完整 API 说明

## 示例脚本

- **`example/control_sdk_examples/joycon_control_example.py`**  
  **用途：** 基础连接测试工具。  
  **功能：** 仅用于测试手柄与电脑的蓝牙连接及按键响应，不涉及机械臂控制。用于排查手柄连接问题。

- **`example/test_joycon_arm_control.py`**  
  **用途：** 全功能手柄控制台。  
  **功能：** 包含完整的机械臂控制功能，支持模式切换（关节/笛卡尔）、速度调节、夹爪控制，并提供实时状态显示和交互式连接向导。

- **`example/test_joycon_display.py`**  
  **用途：** 手柄状态可视化监控。

- **`example/control_sdk_examples/joycon_control_example.py`**  
  **用途：** 完整的手柄控制教学示例。  
  **功能：** 提供分级学习路径，包括连接测试、数据监控、基础控制、姿态模式演示和参数配置。支持姿态模式 TCP模式 / 关节模式 的演示。

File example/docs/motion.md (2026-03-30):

# MotionSDK - 运动控制

**对应源码：** `Embodied_SDK/motion.py`

## 概述

`MotionSDK` 提供机械臂的基础运动控制能力，支持关节空间运动、笛卡尔空间运动、预设动作和夹爪控制。

当前版本说明：
- `move_cartesian()` 默认使用 `config/dh_parameters_config.json` 创建 IK/FK 模型
- 该配置会统一影响 SDK 中的位姿查询、视觉抓取、JoyCon 默认运动学与 MuJoCo 默认运动学
- 如需读取当前 SDK 实际使用的运动学配置，可通过 `HorizonArmSDK.get_kinematics_config()` 或 `load_kinematics_config()` 查询

## 模块入口

### 通过顶层 SDK（推荐）

```python
from Embodied_SDK import HorizonArmSDK

sdk = HorizonArmSDK(motors=motors)
motion = sdk.motion  # 获取 MotionSDK 实例
kin_cfg = sdk.get_kinematics_config()  # 查看当前统一 DH / joint_offsets / joint_limits 配置
```

### 独立使用

```python
from Embodied_SDK import MotionSDK, load_kinematics_config

motion = MotionSDK()
motion.bind_motors(motors, use_motor_config=True)
kin_cfg = load_kinematics_config()
```

---

## 核心接口

### 1. 绑定电机

#### `bind_motors(motors, use_motor_config=True, reducer_ratios=None, directions=None)`

**参数：**
- `motors`: 电机字典 `{motor_id: controller}`
- `use_motor_config`: 是否从配置文件加载参数（默认 True）
- `reducer_ratios`: 手动指定减速比 `{motor_id: ratio}`
- `directions`: 手动指定方向 `{motor_id: 1或-1}`

**示例：**
```python
# 使用配置文件
motion.bind_motors(motors, use_motor_config=True)

# 手动指定参数
motion.bind_motors(
    motors,
    use_motor_config=False,
    reducer_ratios={1: 50.0, 2: 50.0, 3: 36.0, 4: 36.0, 5: 36.0, 6: 36.0},
    directions={1: 1, 2: -1, 3: 1, 4: 1, 5: 1, 6: 1}
)
```

---

### 2. 设置运动参数

#### `set_motion_params(max_speed=100, acceleration=50, deceleration=50)`

设置全局运动参数，影响后续所有运动指令。

**参数：**

| 参数 | 默认值 | 推荐范围 | 说明 |
|---|---|---|---|
| `max_speed` | 500 | 100-800 | 最大速度（RPM），与当前版本上位机/SDK 一致 |
| `acceleration` | 1000 | 100-2000 | 加速度（RPM/s） |
| `deceleration` | 1000 | 100-2000 | 减速度（RPM/s） |

**⚠️ 注意：**
- 首次使用建议设置较低值（如 speed=200、acceleration=500）
- 速度过高可能导致电机堵转或精度下降

**示例：**
```python
# 安全的初始设置
sdk.motion.set_motion_params(max_speed=200, acceleration=500, deceleration=500)

# 正常运行设置（与软件内梯形曲线默认一致）
sdk.motion.set_motion_params(max_speed=500, acceleration=1000, deceleration=1000)
```

---

### 3. 关节空间运动

#### `move_joints(joint_angles, duration=None) -> bool`

控制机械臂运动到指定关节角度。

**参数：**
- `joint_angles`: 6 个关节角度列表 `[J1, J2, J3, J4, J5, J6]`（度）
- `duration`: 运动时间（秒），None 表示使用默认速度

**返回值：**
- `True`: 运动指令发送成功
- `False`: 运动失败

**⚠️ 安全提示：**
- 关节角度以机械零位为基准，确保已正确设置零点
- 确保角度在安全范围内（参考 `config/motor_config.json`）
- 首次运动建议使用小角度增量测试

**示例：**
```python
# 回到初始位置
sdk.motion.move_joints([0, 0, 0, 0, 0, 0], duration=2.0)

# 抬起大臂
sdk.motion.move_joints([0, 45, 0, 0, 0, 0], duration=1.5)

# 复杂姿态
sdk.motion.move_joints([30, 45, -30, 0, 15, 0], duration=3.0)
```

---

### 4. 笛卡尔空间运动

#### `move_cartesian(position, orientation=None, duration=None) -> bool`

控制机械臂末端运动到指定笛卡尔坐标。

**参数：**
- `position`: 末端位置 `[x, y, z]`（毫米）
- `orientation`: 末端姿态 `[yaw, pitch, roll]`（度）
- `duration`: 运动时间（秒）

**坐标系：**
- 原点：机械臂基座中心
- X 轴：向前，Y 轴：向左，Z 轴：向上

**⚠️ 注意：**
- 笛卡尔运动依赖逆运动学求解，可能存在无解情况
- 确保目标位置在机械臂可达工作空间内
- 避免奇异点附近的运动

**示例：**
```python
# 移动到前方 300mm，高度 200mm
sdk.motion.move_cartesian([300, 0, 200])

# 指定位置和姿态
sdk.motion.move_cartesian(
    position=[250, 100, 300],
    orientation=[0, 0, 180],
    duration=2.0
)
```

---

### 5. 预设动作

#### `execute_preset_action(name, speed="normal") -> bool`

执行预定义的动作序列。

**参数：**
- `name`: 动作名称（在 `config/embodied_config/preset_actions.json` 中定义）
- `speed`: 速度模式 `"slow"` | `"normal"` | `"fast"`

**常用预设动作：**
- `home`: 回到初始位置
- `sleep`: 收纳姿态
- `wave`: 挥手动作
- `pick`: 抓取准备姿态

**示例：**
```python
# 回到初始位置
sdk.motion.execute_preset_action("home", speed="normal")

# 快速执行挥手动作
sdk.motion.execute_preset_action("wave", speed="fast")
```

---

### 6. 夹爪控制

#### `control_claw(action) -> bool`

控制夹爪开合。

**参数：**
- `action`: `1` = 张开，`0` = 闭合

**示例：**
```python
import time

# 张开夹爪
sdk.motion.control_claw(action=1)
time.sleep(1)

# 闭合夹爪
sdk.motion.control_claw(action=0)
```

#### `set_claw_params(open_angle=None, close_angle=None)`

设置夹爪开合角度。

```python
sdk.motion.set_claw_params(open_angle=90, close_angle=0)
```

#### `get_claw_params() -> dict`

获取当前夹爪参数。

```python
params = sdk.motion.get_claw_params()
print(f"张开: {params['open']}°, 闭合: {params['close']}°")
```

---

## 完整示例

```python
import time
from Embodied_SDK import HorizonArmSDK, create_motor_controller

# 1. 连接电机
motors = {mid: create_motor_controller(motor_id=mid, port="COM14") for mid in range(1, 7)}
for m in motors.values():
    m.connect()

# 2. 初始化 SDK
sdk = HorizonArmSDK(motors=motors)

# 3. 设置运动参数
sdk.motion.set_motion_params(max_speed=100, acceleration=80, deceleration=80)

# 4. 执行运动
sdk.motion.move_joints([0, 90, 0, 0, 0, 0], duration=2.0)
time.sleep(2)

sdk.motion.move_cartesian([300, 0, 200])
time.sleep(2)

# 5. 控制夹爪
sdk.motion.control_claw(action=1)
time.sleep(1)
sdk.motion.control_claw(action=0)

# 6. 清理
for m in motors.values():
    m.disconnect()
```

---

## 配置文件

### motor_config.json

`MotionSDK` 从 `config/motor_config.json` 加载电机参数：

```json
{
  "motors": {
    "1": {
      "name": "基座关节",
      "reducer_ratio": 50.0,
      "direction": 1,
      "min_angle": -180,
      "max_angle": 180
    }
  }
}
```

**设置配置目录：**
```python
import os
os.environ['HORIZONARM_CONFIG_DIR'] = '/path/to/your/config'
```

---

## 相关文档

- [快速入门](quickstart.md) - 基础使用教程
- [安全须知](safety.md) - 安全操作指南
- [配置说明](configuration.md) - 配置文件详解
- [API 详细参考](api_detailed.md) - 完整 API 说明

## 示例脚本

- `example/sdk_quickstart.py` - 基础运动示例
- `example/test_multi_motor_sync.py` - 多电机同步示例

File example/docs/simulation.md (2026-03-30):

# DigitalTwinSDK - 数字孪生与仿真

**对应源码：** `Embodied_SDK/digital_twin.py`

## 概述

`DigitalTwinSDK` 提供基于 MuJoCo 的数字孪生仿真能力，支持在虚拟环境中测试机械臂运动，无需连接真实硬件。

说明：
- 仿真能力属于 **脚本/SDK 可选能力**，不要求在 UI 中使用；
- 若你当前版本的 UI 已移除 MuJoCo 仿真页面，依然可以通过本页的脚本方式使用 `DigitalTwinSDK`。

## 前置条件

- （可选）安装 `mujoco` 包：`pip install mujoco`
- URDF 模型文件存在：`config/urdf/`
- 显卡支持 OpenGL

---

## 模块入口

### 通过顶层 SDK

```python
from Embodied_SDK import HorizonArmSDK

sdk = HorizonArmSDK(motors=motors)
dt = sdk.digital_twin  # 获取 DigitalTwinSDK 实例
```

### 独立使用

```python
from Embodied_SDK import DigitalTwinSDK

dt = DigitalTwinSDK()
```

---

## 核心接口

### 1. 启动/停止仿真

#### `start_simulation() -> bool`

启动 MuJoCo 仿真环境。

**返回值：**
- `True`: 仿真启动成功
- `False`: 启动失败（MuJoCo 未安装或 URDF 文件缺失）

**示例：**
```python
if dt.start_simulation():
    print("✅ 仿真已启动")
else:
    print("❌ 仿真启动失败")
```

#### `stop_simulation()`

停止仿真环境。

```python
dt.stop_simulation()
```

#### `is_running() -> bool`

检查仿真是否正在运行。

```python
if dt.is_running():
    print("仿真正在运行")
```

---

### 2. 仿真运动

仿真 SDK 的运动接口与 `MotionSDK` 一致：

#### `move_joints(joint_angles, duration=None) -> bool`

在仿真中运动到指定关节角度。

**参数：**
- `joint_angles`: 6 个关节角度 `[J1, J2, J3, J4, J5, J6]`（度）
- `duration`: 运动时间（秒）

**示例：**
```python
dt.move_joints([0, 30, -45, 0, 15, 0], duration=2.0)
```

#### `move_cartesian(position, orientation=None, duration=None) -> bool`

在仿真中进行笛卡尔空间运动。

**参数：**
- `position`: 末端位置 `[x, y, z]`（毫米）
- `orientation`: 末端姿态 `[yaw, pitch, roll]`（度）
- `duration`: 运动时间（秒）

**示例：**
```python
dt.move_cartesian([300, 0, 200], orientation=[0, 0, 180])
```

#### `execute_preset_action(name, speed="normal") -> bool`

在仿真中执行预设动作。

**示例：**
```python
dt.execute_preset_action("wave_hand", speed="normal")
dt.execute_preset_action("home_position", speed="fast")
```

---

### 3. 直接设置关节角

#### `set_joint_angles(angles) -> bool`

直接设置关节角度（无运动过程，瞬时切换）。

**用途：**
- 同步真实机械臂状态到仿真
- 生成运动波形演示
- 快速切换姿态

**参数：**
- `angles`: 6 个关节角度（度）

**示例：**
```python
# 瞬间切换到指定姿态
dt.set_joint_angles([0, 90, 0, 0, 0, 0])

# 同步真实机械臂状态
real_angles = [m.read_parameters.get_position() for m in motors.values()]
dt.set_joint_angles(real_angles)
```

---

### 4. 轨迹管理

#### `clear_trajectory() -> bool`

清空轨迹记录。

```python
dt.clear_trajectory()
```

---

### 5. 运动参数设置

#### `set_motion_params(max_speed=200, acceleration=100, deceleration=100)`

设置仿真运动参数。

```python
dt.set_motion_params(max_speed=200, acceleration=100, deceleration=100)
```

---

## 完整示例

### 基础仿真测试

```python
from Embodied_SDK import DigitalTwinSDK
import time

# 1. 创建仿真 SDK
dt = DigitalTwinSDK()

# 2. 启动仿真
if not dt.start_simulation():
    print("仿真启动失败")
    exit(1)

print("✅ 仿真已启动")

# 3. 设置运动参数
dt.set_motion_params(max_speed=200, acceleration=100, deceleration=100)

# 4. 执行运动测试
print("测试关节运动...")
dt.move_joints([0, 30, -45, 0, 15, 0], duration=2.0)
time.sleep(2)

print("测试笛卡尔运动...")
dt.move_cartesian([300, 0, 200], duration=2.0)
time.sleep(2)

print("测试预设动作...")
dt.execute_preset_action("wave_hand")
time.sleep(3)

# 5. 停止仿真
dt.stop_simulation()
print("✅ 仿真已停止")
```

---

### 仿真与真实机械臂同步

```python
from Embodied_SDK import HorizonArmSDK, create_motor_controller
import time

# 1. 连接真实机械臂
motors = {mid: create_motor_controller(motor_id=mid, port="COM14") for mid in range(1, 7)}
for m in motors.values():
    m.connect()

# 2. 初始化 SDK
sdk = HorizonArmSDK(motors=motors)

# 3. 启动仿真
sdk.digital_twin.start_simulation()

# 4. 同步循环
try:
    while True:
        # 读取真实机械臂当前角度
        real_angles = []
        for mid in range(1, 7):
            angle = motors[mid].read_parameters.get_position()
            real_angles.append(angle)
        
        # 同步到仿真
        sdk.digital_twin.set_joint_angles(real_angles)
        
        time.sleep(0.1)  # 10Hz 更新
        
except KeyboardInterrupt:
    print("\n停止同步")
    
# 5. 清理
sdk.digital_twin.stop_simulation()
for m in motors.values():
    m.disconnect()
```

---

### 先在仿真中测试，再在真实机械臂上执行

```python
from Embodied_SDK import HorizonArmSDK

# 1. 在仿真中测试
dt = HorizonArmSDK(motors={}).digital_twin
dt.start_simulation()

print("在仿真中测试运动...")
test_angles = [0, 45, -30, 0, 15, 0]
dt.move_joints(test_angles, duration=2.0)
time.sleep(2)

print("仿真测试成功，准备在真实机械臂上执行...")
dt.stop_simulation()

# 2. 连接真实机械臂并执行相同运动
motors = {mid: create_motor_controller(motor_id=mid, port="COM14") for mid in range(1, 7)}
for m in motors.values():
    m.connect()

sdk = HorizonArmSDK(motors=motors)
sdk.motion.move_joints(test_angles, duration=2.0)

for m in motors.values():
    m.disconnect()
```

---

## 使用场景

1. **算法验证**：
   - 在仿真中验证运动规划算法
   - 测试轨迹是否合理

2. **培训演示**：
   - 不需要真实机械臂也能演示功能
   - 培训新用户时更安全

3. **开发测试**：
   - 快速迭代代码
   - 避免反复连接硬件

4. **数字孪生**：
   - 实时同步真实机械臂状态
   - 可视化监控运动过程

---

## 注意事项

1. **仿真限制**：
   - 仿真运动不会影响真实机械臂
   - 物理参数（摩擦力、惯性等）可能与真实环境有差异

2. **性能要求**：
   - MuJoCo 需要显卡支持 OpenGL
   - 低配置电脑可能运行卡顿

3. **模型文件**：
   - URDF 模型需与真实机械臂参数一致
   - 修改 URDF 后需重启仿真

---

## 相关文档

- [MotionSDK](motion.md) - 运动控制接口（仿真接口与之一致）
- [安全须知](safety.md) - 真实机械臂安全操作指南
- [配置说明](configuration.md) - URDF 模型配置

## 示例脚本

- **`example/mujoco_control.py`**  
  **用途：** MuJoCo 仿真交互式演示。  
  **功能：** 提供菜单选择，支持自动波形演示、预设动作执行和随机姿态生成，展示仿真 SDK 的基本控制能力。

- **`example/control_sdk_examples/digital_twin_example.py`**  
  **用途：** 教学版最短示例（跑通核心 API：`start_simulation/move_joints/move_cartesian/execute_preset_action`）。  

- **`example/developer_tools/mujoco_slider_viewer.py`**  
  **用途：** 底层调试工具（直接操作 `mujoco.viewer` 的滑块与 `data.ctrl/qpos`），不代表推荐 SDK 用法。

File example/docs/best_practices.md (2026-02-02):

# 最佳实践

本页总结在“真实机械臂 + 上位机/脚本控制”场景下的常用经验，目标是 **更安全、更稳定、更易排查**。

---

## 1. 安全优先

- **首次上电/首次运行**：把速度降到最低（例如 `max_speed=50~100`），先做小幅度单轴测试
- **不要依赖软件急停**：真实风险请使用物理急停/断电
- **谨慎使用 `disable()`**：无抱闸机械臂可能下坠；多数场景用 `stop()` 更安全

---

## 2. 配置要“可追溯”

- 把关键参数放进 `config/`：
  - `motor_config.json`（减速比/方向）
  - `embodied_config/preset_actions.json`（预设动作）
  - `aisdk_config.yaml`（AI）
- 不要把密钥写进仓库：使用环境变量注入（见 `configuration.md`）

---

## 3. 连接与资源管理

- 单进程内建议 **复用同一串口端口**（UCP 连接池会自动复用）
- 多脚本/多进程同时访问同一串口容易冲突：尽量确保同一时间只有一个控制程序在跑

---

## 4. 多电机同步建议

- 推荐使用 **Y42 聚合同步**（一次通信下发多电机指令）：
  - `ZDTMotorController.y42_sync_enable`
  - `ZDTMotorController.y42_sync_position`
  - `ZDTMotorController.y42_sync_speed`
- 旧的 `multi_sync + sync_motion` 方案仅用于兼容，不建议新项目依赖

---

## 5. 日志与排障

- 开发阶段建议开启 INFO/DEBUG 日志（示例：`example/control_sdk_examples/motor_usage_example.py`）
- 遇到“到位失败/方向反/角度不对”优先检查：
  - `config/motor_config.json` 的 `motor_directions` / `motor_reducer_ratios`
  - 回零/零点是否正确

更多排查见：[troubleshooting.md](troubleshooting.md)

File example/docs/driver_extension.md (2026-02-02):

# 驱动扩展

本章节面向需要接入不同厂商/不同协议驱动板的开发者，说明如何扩展电机驱动实现，并让上层继续使用统一的 `motors` 字典。

## 1. 目标与原则

- **目标**：让上层始终只依赖统一的“电机控制器接口”，无需关心实际连接的驱动板型号。
- **原则**：
  - 上层逻辑只拿到 `motors: Dict[int, MotorController]`
  - 控制器需要实现一组最小方法（连接、断开、多机命令、同步等）
  - 新驱动通过“注册机制”接入，做到可插拔

## 2. 统一使用方式

建议保持以下写法（无论使用哪种驱动）：

- `motors` 字典结构固定：`{motor_id: controller_instance}`
- 交给 `HorizonArmSDK` 或各子 SDK 绑定即可：
  - `sdk = HorizonArmSDK(motors=motors)`
  - 或 `sdk.motion.bind_motors(motors)` / `sdk.vision.bind_motors(motors)`

## 3. 驱动扩展的“注册”方式

系统提供了统一的驱动注册入口：

- `Horizon_Core.gateway.register_motor_driver(name, controller_cls, protocol_type="ucp")`
- `Horizon_Core.gateway.set_default_motor_driver(name)`

其中：
- `controller_cls`：你的电机控制器类（负责连接、发命令、读状态等）
- `protocol_type`：协议类型（当前项目主要为 `"ucp"`）

> 如果你的驱动板协议与现有命令体系差异很大，可以只实现 `controller_cls`，并在控制器类里自行处理协议帧。

## 4. 控制器需要实现哪些能力

电机控制器需要满足上层调用的最小能力集合：

### 4.1 连接管理

- `connect(motor_id: Optional[int] = None) -> None`
- `disconnect() -> None`

说明：
- 支持“构造时指定 motor_id”或“connect 时指定 motor_id”
- 多电机场景建议支持共享通信接口（同一条总线、多实例共享）

### 4.2 单电机控制能力（最小）

上层常用到的最小能力（用于关节控制/末端控制的下发）：

- `enable() -> None`
- `disable() -> None`
- `move_to_position(position: float, **kwargs) -> None`
- `get_position() -> float`
- `is_in_position() -> bool`

> `**kwargs` 的存在是为了让不同驱动板可以扩展自己的速度/加速度/绝对/相对等参数，同时不破坏统一接口。

### 4.3 多电机同步能力（推荐）

为了支持“多电机同起同停”的一致性（更好的轨迹一致性与手感），建议提供：

- `multi_motor_command(per_motor_commands: list, expected_ack_motor_id: int = 1, timeout: float = 1.0, wait_ack: bool = True, mode: str = None)`

说明：
- 若你的驱动板支持“聚合帧一次下发多电机命令”，可实现 `multi_motor_command`
- 本项目（UCP / OmniCAN）**不再允许**“multi_sync + sync_motion 广播触发”旧方案；底层 `sync_motion()` 已被禁用以防误用

## 5. 推荐的接入步骤

1. **实现你的控制器类**：满足第 4 节的最小接口
2. **（可选）实现 builder/parser**：把协议帧构建与解析拆出去，便于维护与复用
3. **注册驱动**：
   - `gateway.register_motor_driver("your_driver", YourController, protocol_type="ucp")`
4. **（可选）设置默认驱动**：
   - `gateway.set_default_motor_driver("your_driver")`
5. **在业务侧创建 motors**：
   - 使用 `create_motor_controller(..., driver_type="your_driver")`（如果你选择走统一工厂）
   - 或直接实例化你的 `YourController(...)`

## 6. 常见坑与建议

- **motor_id 统一约定**：建议仍使用 1-6 映射到 J1-J6（或你的实际关节数量），保证上层 `move_joints([J1..J6])` 的语义不变。
- **单位统一**：上层通常以“度/毫米/秒”为单位，你的驱动可以自由换算，但建议在控制器层把单位统一好，减少上层误用。
- **线程安全**：如果你允许多线程读取状态/下发命令，请在底层通信层做串行化（避免命令与响应交叉）。
- **超时与降级**：某些设备在特定响应模式下不会回 ACK，建议允许 `wait_ack=False` 并做好降级发送策略。

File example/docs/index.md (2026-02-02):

# HorizonArm SDK 开发者文档

欢迎使用 HorizonArm SDK！这是专为机械臂二次开发设计的纯 Python 接口库。

---

## 设计理念

- **核心驱动**：底层算法与通信逻辑由 `Horizon_Core` 提供，确保系统稳定性
- **逻辑解耦**：SDK 为逻辑层驱动，不依赖图形界面，可在 Ubuntu、ROS2 或纯脚本环境中运行
- **开发优先**：通过 `Embodied_SDK` 提供标准的 Python 调用方式，降低开发门槛

---

## 项目结构

典型的开发项目目录结构：

```
HorizonArm_Project/
├── Horizon_Core/         # 核心驱动组件
│   ├── __init__.py       # 公开接口定义
│   ├── Control_SDK/      # 电机控制SDK
│   ├── AI_SDK/           # AI服务SDK
│   └── ...               # 其他核心模块
├── Embodied_SDK/         # 开发者接口层（源码）
│   ├── __init__.py
│   ├── horizon_sdk.py    # 顶层入口
│   ├── motion.py         # 运动控制
│   ├── visual_grasp.py   # 视觉抓取
│   ├── joycon.py         # 手柄控制
│   ├── digital_twin.py   # 数字孪生
│   ├── embodied.py       # 具身智能
│   └── io.py             # IO控制
├── config/               # 配置文件
│   ├── motor_config.json
│   ├── aisdk_config.yaml
│   └── embodied_config/
└── your_script.py        # 你的开发代码
```

---

## HorizonArmSDK - 顶层入口

**对应源码：** `Embodied_SDK/horizon_sdk.py`

`HorizonArmSDK` 是推荐的统一入口，它聚合了所有子 SDK，提供一站式访问能力。

### 初始化

```python
from Embodied_SDK import HorizonArmSDK, create_motor_controller

# 1. 创建电机字典
motors = {mid: create_motor_controller(motor_id=mid, port="COM14") for mid in range(1, 7)}
for m in motors.values():
    m.connect()

# 2. 初始化顶层 SDK
sdk = HorizonArmSDK(
    motors=motors,      # 电机字典（必需）
    camera_id=0         # 相机编号（可选，用于视觉功能）
)
```

### 子模块访问

创建 `HorizonArmSDK` 后，可直接访问以下子模块：

| 属性 | 类型 | 对应文档 | 功能 |
|---|---|---|---|
| `sdk.motion` | [MotionSDK](motion.md) | [文档](motion.md) | 关节/末端运动、夹爪、预设动作 |
| `sdk.vision` | [VisualGraspSDK](vision.md) | [文档](vision.md) | 像素点抓取、框选抓取 |
| `sdk.follow` | [FollowGraspSDK](vision.md) | [文档](vision.md) | 视觉跟随、目标跟踪 |
| `sdk.joycon` | [JoyconSDK](joycon.md) | [文档](joycon.md) | Joy-Con 手柄控制 |
| `sdk.digital_twin` | [DigitalTwinSDK](simulation.md) | [文档](simulation.md) | MuJoCo 仿真 |
| `sdk.embodied` | [EmbodiedSDK](embodied.md) | [文档](embodied.md) | 自然语言控制 |
| `sdk.io` | [IOSDK](io.md) | [文档](io.md) | ESP32 IO 控制 |

---

## 快速示例

```python
from Embodied_SDK import HorizonArmSDK, create_motor_controller
import time

# 初始化
motors = {mid: create_motor_controller(motor_id=mid, port="COM14") for mid in range(1, 7)}
for m in motors.values():
    m.connect()

sdk = HorizonArmSDK(motors=motors)

# 运动控制
sdk.motion.move_joints([0, 90, 0, 0, 0, 0], duration=2.0)
time.sleep(2)

# 视觉抓取
sdk.vision.grasp_at_pixel(320, 240)

# 自然语言控制
sdk.embodied.run_nl_instruction("机械臂回到初始位置")

# 清理
for m in motors.values():
    m.disconnect()
```

---

## 核心功能模块

### 1. 运动控制 - [MotionSDK](motion.md)

提供机械臂基础运动能力：

- 关节空间运动
- 笛卡尔空间运动
- 预设动作执行
- 夹爪控制

**查看详情：** [运动控制文档](motion.md)

---

### 2. 视觉抓取 - [VisualGraspSDK](vision.md)

提供视觉相关能力：

- 像素点抓取
- 框选抓取
- 目标检测跟随
- 手动框选跟踪

**查看详情：** [视觉抓取文档](vision.md)

---

### 3. 手柄控制 - [JoyconSDK](joycon.md)

提供 Joy-Con 手柄控制：

- 关节模式
- 笛卡尔模式
- 模式切换
- 速度调节

**查看详情：** [手柄控制文档](joycon.md)

---

### 4. 数字孪生 - [DigitalTwinSDK](simulation.md)

提供 MuJoCo 仿真能力：

- 虚拟环境测试
- 运动可视化
- 算法验证
- 状态同步

**查看详情：** [仿真文档](simulation.md)

---

### 5. 具身智能 - [EmbodiedSDK](embodied.md)

提供自然语言控制：

- AI 理解指令
- 自动规划执行
- 复杂任务分解
- 流式反馈

**查看详情：** [具身智能文档](embodied.md)

---

### 6. IO 控制 - [IOSDK](io.md)

提供 ESP32 IO 控制：

- 数字输入读取
- 数字输出控制
- 传感器接入
- 外设联动

**查看详情：** [IO 控制文档](io.md)

---

## 开发流程建议

### 新手入门（5 步）

1. **环境准备**：[安装与环境](installation.md)
2. **⚠️  安全学习**：[安全须知](safety.md)（必读）
3. **快速上手**：[快速入门](quickstart.md)
4. **功能学习**：选择你需要的功能模块文档
5. **参考 API**：[API 详细参考](api_detailed.md)

### 开发路径

```
第 1 天：环境安装 + 安全须知 + 快速入门
第 2-3 天：学习运动控制 + 实践基础运动
第 4-5 天：学习视觉抓取 OR 手柄控制（按需选择）
第 6-7 天：学习具身智能 OR 仿真（按需选择）
第 7+ 天：开始实际项目开发
```

---

## 文档导航

### 入门必读
- [安装与环境](installation.md) - 环境配置
- [⚠️  安全须知](safety.md) - 安全操作（必读）
- [快速入门](quickstart.md) - 10 分钟上手
- [核心概念](concepts.md) - 统一术语
- [配置说明](configuration.md) - 配置文件

### 功能模块
- [MotionSDK - 运动控制](motion.md)
- [VisualGraspSDK - 视觉抓取](vision.md)
- [JoyconSDK - 手柄控制](joycon.md)
- [DigitalTwinSDK - 仿真](simulation.md)
- [EmbodiedSDK - 具身智能](embodied.md)
- [IOSDK - IO 控制](io.md)

### 扩展与参考
- [驱动扩展](driver_extension.md) - 多厂商驱动板接入
- [API 快速参考](api_reference.md) - 接口速查
- [API 详细参考](api_detailed.md) - 完整 API 说明
- [常见问题](troubleshooting.md) - 故障排查

---

## 示例脚本

在 `example/` 目录下提供了丰富的示例：

| 示例文件 | 功能 |
|---|---|
| `quickstart_guide.py` | 5分钟入门：连接单电机、读状态、简单运动 |
| `sdk_quickstart.py` | 交互式完整示例：6轴基础运动/夹爪/预设动作 |
| `test_gripper_torque.py` | 夹爪（电机ID=7）力矩模式测试（clamp/open） |
| `control_sdk_examples/joycon_control_example.py` | Joy-Con 手柄遥操作（分级教学） |
| `control_sdk_examples/visual_grasp_example.py` | 视觉抓取示例（点/框抓取） |
| `control_sdk_examples/io_control_example.py` | IO 控制示例 |
| `mujoco_control.py` | MuJoCo 仿真交互演示（可选） |
| `test_multi_motor_sync.py` | 多电机同步（完整版/诊断版） |
| `ai_sdk_examples/` | AI 功能示例（10+ 个） |

---

## 获取帮助

- **文档首页**：你正在查看
- **快速入门**：[quickstart.md](quickstart.md)
- **安全须知**：[safety.md](safety.md)
- **故障排查**：[troubleshooting.md](troubleshooting.md)

---

**祝你开发愉快！** 🚀

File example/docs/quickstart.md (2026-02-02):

# 快速入门

⚠️  **首次使用前必读：** 请先阅读 [安全须知](safety.md)，确保回零参数正确设置！

---

## 一、环境准备

### 1.1 系统要求

- **Python 版本**：必须 3.12+（低于 3.12 可能导致兼容性问题）
- **操作系统**：Windows 10/11，Ubuntu 20.04+
- **硬件**：OmniCAN（UCP 模式，电脑侧表现为串口），USB 摄像头（可选）

### 1.2 安装依赖

```bash
# 进入项目根目录（包含 requirements.txt）
# 例如：cd Horizon_Arm2.0

# 安装依赖
pip install -r requirements.txt
```

**核心依赖：**
- `pyserial`：串口通信
- `opencv-contrib-python`：相机采集与视觉处理（包含跟踪器）
- `numpy`：数值计算
- `mujoco`：仿真（可选）

### 1.3 硬件连接

1. **连接 OmniCAN（UCP模式）**到电脑 USB 口（电脑侧表现为串口）
2. **机械臂上电**
3. **查看串口号**：
   - Windows：设备管理器 → 端口 → 记下 `COM14` 这样的编号
   - Linux：通常是 `/dev/ttyUSB0`

### 1.4 配置文件

**配置目录：** `config/`

建议设置环境变量指向配置目录（**打包部署/外置配置**场景用；源码开发默认直接用本项目的 `./config/`）：

```python
import os
os.environ['HORIZONARM_CONFIG_DIR'] = '/path/to/your/config'
```

**主要配置文件：**

| 文件 | 用途 |
|---|---|
| `motor_config.json` | 电机减速比、方向、限位 |
| `calibration_parameter.json` | 相机标定参数 |
| `embodied_config/preset_actions.json` | 预设动作 |
| `aisdk_config.yaml` | AI API 配置 |

---

## 二、核心概念

### 2.1 motors 字典

SDK 以 `motors` 字典作为机械臂控制的基础上下文：

- **结构**：`{motor_id: motor_controller}`
- **motor_id**：电机地址（1-6 对应 6 轴）
- **motor_controller**：电机控制器实例

```python
from Embodied_SDK import create_motor_controller

motors = {mid: create_motor_controller(motor_id=mid, port="COM14") for mid in range(1, 7)}
for m in motors.values():
    m.connect()
```

### 2.2 顶层入口与子模块

`HorizonArmSDK` 是推荐的统一入口：

```python
from Embodied_SDK import HorizonArmSDK

sdk = HorizonArmSDK(motors=motors, camera_id=0)
```

**子模块：**
- `sdk.motion` - 运动控制
- `sdk.vision` - 视觉抓取
- `sdk.follow` - 视觉跟随
- `sdk.joycon` - 手柄控制
- `sdk.digital_twin` - 仿真
- `sdk.embodied` - 自然语言控制
- `sdk.io` - IO 控制

### 2.3 坐标与单位约定

| 参数 | 单位 | 说明 |
|---|---|---|
| 关节角度 | 度（deg） | [J1, J2, J3, J4, J5, J6] |
| 末端位置 | 毫米（mm） | [x, y, z] |
| 末端姿态 | 度（deg） | [yaw, pitch, roll] |

---

## 三、⚠️  回零参数设置（极其重要）

**机械臂在首次使用前，必须确认回零参数是否正确。回零参数错误可能导致机械臂损坏！**

### 3.1 快速检查

```python
from Embodied_SDK import create_motor_controller

motor = create_motor_controller(motor_id=1, port="COM14")
motor.connect()

# 查询当前位置
pos = motor.read_parameters.get_position()
print(f"当前位置: {pos}°")
```

### 3.2 手动设置零点（首次使用必做）

```python
# 1. 手动将关节调整到机械零位
#    （通常是关节的中间位置，或者有物理标记的位置）

# 2. 执行以下命令将当前位置设为零点
motor.homing_commands.set_zero_position(save_to_chip=True)
print("✅ 零点已设置并保存")

# 3. 对所有 6 个关节重复此操作
```

**详细步骤请查看：[安全须知 - 回零参数检查](safety.md#1-回零参数检查极其重要)**

### 3.3 首次运动安全检查清单

- [ ] 清空机械臂周围障碍物
- [ ] 手放在急停按钮附近
- [ ] 首次运动使用低速（speed=50）
- [ ] 先测试单个关节小角度运动（±10度）
- [ ] 确认运动方向正确后再增大幅度

---

## 四、第一个程序（4 步）

### 步骤 1：启动程序

```bash
python example/quickstart_guide.py
```

### 步骤 2：交互式配置

程序启动后，会首先询问硬件连接信息：

```text
[配置] 连接机械臂电机
------------------------------
请输入串口号 (默认 COM14): 
```

1.  输入你的串口号（如 `COM3` 或 `/dev/ttyUSB0`），直接回车使用默认值。
2.  输入电机 ID 列表（默认 1-6），通常直接回车即可。

### 步骤 3：功能菜单选择

配置完成后，将显示主功能菜单（`sdk_quickstart.py` 的交互菜单会更完整）：

```text
======================================================================
 🚀 HorizonArm SDK 快速入门 (交互模式)
======================================================================
[1] 关节运动测试 (J1-J6)
[2] 笛卡尔运动测试 (XYZ+RPY)
[3] 夹爪控制测试
[4] 执行预设动作 (Home/Sleep)
[5] 查看电机状态
[0] 退出
----------------------------------------------------------------------
请选择功能 (0-5): 
```

你可以通过输入数字来选择要测试的功能模块。

### 步骤 4：测试流程建议

建议按照以下顺序进行测试：

1.  **查看电机状态 [5]**：确认所有电机电压、温度正常，且位置读数合理。
2.  **关节运动测试 [1]**：会让机械臂进行小幅度的关节运动，验证电机方向和控制链路。
3.  **夹爪控制测试 [3]**：验证夹爪的开合功能。
4.  **预设动作 [4]**：测试 "Home"（回零）和 "Sleep"（收纳）姿态。

---

## 五、完整示例代码

请直接参考 `example/sdk_quickstart.py` 源文件。该文件展示了如何：
1.  **动态连接电机**：通过用户输入灵活配置串口和 ID。
2.  **构建交互式菜单**：使用 `while` 循环和 `input` 处理用户指令。
3.  **调用 SDK 功能**：
    *   `sdk.motion.move_joints()`
    *   `sdk.motion.move_cartesian()`
    *   `sdk.motion.control_claw()`
    *   `sdk.motion.execute_preset_action()`
    *   `sdk.motion.get_motor_status()`

代码片段示例（初始化与菜单循环）：

```python
def main():
    clear_screen()
    print_header()
    
    # 1. 连接向导
    port, motor_ids = connect_motors()
    if not port: return

    # ... (连接逻辑) ...
    
    # 2. 初始化 SDK
    sdk = HorizonArmSDK(motors=motors)
    # 设置安全参数
    sdk.motion.set_motion_params(max_speed=50, acceleration=50, deceleration=50)

    # 3. 主循环
    while True:
        print_menu()
        choice = input("请选择功能 (0-5): ").strip()
        
        if choice == '1':
            test_joint_motion(sdk)
        elif choice == '2':
            test_cartesian_motion(sdk)
        elif choice == '3':
            test_claw(sdk)
        elif choice == '4':
            test_preset_action(sdk)
        elif choice == '5':
            show_motor_status(sdk)
        elif choice == '0':
            break
```

---

## 六、运行示例脚本

项目提供了交互式的示例脚本，请按照屏幕提示操作：

```bash
# 启动快速入门示例
python example/quickstart_guide.py

# 交互式完整示例（6轴机械臂）
python example/sdk_quickstart.py
```

---

## 七、常见问题

### Q1: 机械臂运动方向反了怎么办？

**A:** 立即按急停，然后修改 `config/motor_config.json`：

```json
{
  "motors": {
    "1": {
      "direction": -1  // 改为 -1 反转方向（原来是 1）
    }
  }
}
```

### Q2: 连接失败怎么办？

**A:** 检查：
- 串口号是否正确（Windows 设备管理器）
- CAN 适配器是否连接
- 机械臂是否上电
- 驱动板 CAN 速率是否为 500K

### Q3: 首次运行注意什么？

**A:** 
1. 降低速度（max_speed=50）
2. 小角度测试（±5-10 度）
3. 单轴测试（先测试单个关节）
4. 准备急停（手放在电源开关附近）
5. 清空障碍（确保工作区域安全）

---

## 八、下一步

- **必读**：[安全须知](safety.md) - 详细的安全操作指南
- **学习模块**：
  - [MotionSDK - 运动控制](motion.md)
  - [VisualGraspSDK - 视觉抓取](vision.md)
  - [JoyconSDK - 手柄控制](joycon.md)
  - [DigitalTwinSDK - 仿真](simulation.md)
  - [EmbodiedSDK - 具身智能](embodied.md)
  - [IOSDK - IO 控制](io.md)
- **参考**：[API 参考](api_reference.md) - 接口速查
- **故障排查**：[常见问题](troubleshooting.md)

---

**祝你使用愉快！记住：安全第一！** 🛡️

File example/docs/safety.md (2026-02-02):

# ⚠️ 安全须知

## 💀【高危警告】关于电机失能 (Disable)

### 🚨 重要警告

**如果您使用的机械臂电机没有物理抱闸（刹车）功能，请特别注意：**

- **❌ 严禁在代码中随意调用 `motor.control_actions.disable()` 接口！**
- **❌ 严禁在程序退出时自动失能！**
- **❌ 严禁在停止运动时使用失能！**
- **❌ 严禁在机械臂悬空状态下失能！**

### ⚠️ 失能的后果（无刹车电机）

对于**没有机械刹车的电机**，一旦失能，关节将**瞬间失去力矩锁止能力**。在重力作用下，机械臂会**立即掉落**，导致：

1. **机械臂砸到桌面** → 关节、连杆损坏
2. **末端执行器/夹爪砸坏** → 相机、传感器损坏  
3. **可能砸伤操作人员** → 手指、手臂受伤
4. **桌面砸坏** → 工作台损坏

### ✅ 正确做法

| 场景 | ❌ 错误做法 | ✅ 正确做法 |
|---|---|---|
| **程序退出** | `motor.disable()` | `motor.disconnect()` - 仅断开通信，保持使能 |
| **紧急停止** | `motor.disable()` | `motor.stop()` - 停止运动，保持使能 |
| **长时间不用** | `motor.disable()` | `motor.stop()` + 保持使能，或物理断电 |
| **调整位置** | 直接失能 | 先运动到安全姿态（趴下），再断电 |

### 💡 关键概念

- **`stop()`**: 停止运动，但保持电机使能（继续输出力矩锁住位置）✅ 安全
- **`disconnect()`**: 断开通信连接，但电机保持使能状态 ✅ 安全  
- **`disable()`**: 切断电机驱动电流，失去保持力 ❌ 对于无刹车电机极度危险！

### 📋 如何确认您的机械臂是否有刹车？

**有刹车的电机特征：**
- ✅ 断电后关节无法被手动转动（被锁住）
- ✅ 失能后机械臂不会掉落
- ✅ 电机规格书明确标注"带抱闸"或"带刹车"

**无刹车的电机特征：**
- ❌ 断电后关节可以被轻松转动
- ❌ 失能后机械臂会在重力作用下掉落
- ❌ 电机规格书中无刹车相关说明

**⚠️  如果不确定，请按照"无刹车"的安全规范操作！**

### 📝 代码示例

**❌ 错误示例（千万不要这样写）：**
```python
# 错误！退出时失能
try:
    sdk.motion.move_joints([0, 90, 0, 0, 0, 0])
finally:
    for motor in motors.values():
        motor.disable()  # ❌ 错误！机械臂会掉落！
```

**✅ 正确示例：**
```python
# 正确！退出时只断开通信
try:
    sdk.motion.move_joints([0, 90, 0, 0, 0, 0])
finally:
    for motor in motors.values():
        motor.disconnect()  # ✅ 正确！保持使能，仅断开通信
```

---

**在使用 SDK 控制机械臂之前，请务必完整阅读本章节！**

不当的操作可能导致机械臂损坏、人员受伤或设备故障。

---

## 🔴 首次使用前必读

### 1. 回零参数检查（极其重要）

**机械臂在首次使用或更换驱动板后，必须先确认回零参数是否正确。**

#### 为什么回零参数如此重要？

- 机械臂依靠回零来建立坐标系统
- 如果回零参数错误，机械臂会运动到错误的"零点"位置
- 这可能导致机械臂撞击自身或周围物体，造成损坏

#### 如何检查回零参数？

**方法 1：手动确认零点位置**

```python
from Embodied_SDK import create_motor_controller

# 连接 1 号电机（示例）
motor = create_motor_controller(motor_id=1, port="COM14")
motor.connect()

# 查询当前零点位置是否已设置
current_pos = motor.read_parameters.get_position()
print(f"当前位置: {current_pos}°")

# 如果零点不准确，手动调整到正确位置后设置零点
# 1. 先手动（示教模式或小心运动）将关节调整到机械零位
# 2. 执行以下命令将当前位置设为零点
motor.homing_commands.set_zero_position(save_to_chip=True)
print("零点已重新设置并保存")
```

**方法 2：使用限位开关自动回零（推荐，如果驱动板支持）**

```python
# 启动自动回零流程
motor.control_actions.start_homing()

# 等待回零完成（最多 30 秒）
if motor.homing_commands.wait_for_homing_complete(timeout=30):
    print("回零成功")
else:
    print("回零超时，请检查限位开关或手动设置零点")
```

#### ⚠️ 首次回零前的安全措施

1. **清空工作区域**：确保机械臂周围无障碍物
2. **准备急停**：手放在电源开关或急停按钮附近
3. **低速测试**：首次运动使用最低速度（速度参数设为 10-20）
4. **单轴测试**：先测试单个关节，确认方向正确后再测试全部关节
5. **小角度测试**：先运动 5-10 度，确认无异常后再增大幅度

---

## 🟡 日常使用安全规范

### 2. 速度与加速度限制

**不要设置过高的速度或加速度，这可能导致：**
- 电机堵转保护触发
- 机械结构损坏
- 控制精度下降

**推荐参数范围：**（与当前版本上位机/SDK 默认一致）

| 参数 | 最小值 | 推荐值 | 最大值 | 说明 |
|---|---|---|---|---|
| 速度 (speed) | 10 | 200 | 1000 | 单位：RPM |
| 加速度 (acceleration) | 50 | 500-1000 | 2000 | 单位：RPM/s |
| 减速度 (deceleration) | 50 | 500-1000 | 2000 | 单位：RPM/s |

```python
# 设置安全的运动参数（与软件内梯形曲线默认一致）
sdk.motion.set_motion_params(
    max_speed=500,        # 适中速度
    acceleration=1000,    # 平滑加速
    deceleration=1000    # 平滑减速
)
```

### 3. 关节角度限制

**每个关节都有物理限位，超出限位可能损坏机械结构。**

检查你的机械臂的实际限位角度（在 `config/motor_config.json` 中配置）：

```json
{
  "motors": {
    "1": {
      "min_angle": -180,   // 最小角度
      "max_angle": 180     // 最大角度
    }
  }
}
```

**在代码中添加限位检查：**

```python
def safe_move_joints(sdk, target_angles):
    """带限位检查的安全运动函数"""
    # 从配置文件读取限位
    limits = {
        1: (-180, 180),
        2: (-90, 90),
        3: (-135, 135),
        4: (-180, 180),
        5: (-90, 90),
        6: (-180, 180)
    }
    
    # 检查每个关节角度
    for i, angle in enumerate(target_angles, start=1):
        min_ang, max_ang = limits.get(i, (-180, 180))
        if not (min_ang <= angle <= max_ang):
            print(f"⚠️  警告：关节 {i} 的目标角度 {angle}° 超出限位 [{min_ang}, {max_ang}]")
            return False
    
    # 通过检查后再运动
    return sdk.motion.move_joints(target_angles, duration=2.0)
```

### 4. 工作空间限制

**笛卡尔空间运动时，注意机械臂的可达空间：**

```python
# 典型 6 轴机械臂的可达范围（示例，具体参数以实际机械臂为准）
# X 轴：-500mm ~ 500mm
# Y 轴：-500mm ~ 500mm
# Z 轴：0mm ~ 800mm

def check_workspace(x, y, z):
    """检查目标位置是否在工作空间内"""
    if not (-500 <= x <= 500):
        print(f"⚠️  X 坐标 {x} 超出范围")
        return False
    if not (-500 <= y <= 500):
        print(f"⚠️  Y 坐标 {y} 超出范围")
        return False
    if not (0 <= z <= 800):
        print(f"⚠️  Z 坐标 {z} 超出范围")
        return False
    return True

# 使用前检查
if check_workspace(300, 200, 400):
    sdk.motion.move_cartesian([300, 200, 400])
else:
    print("目标位置超出工作空间，已取消运动")
```

### 5. 急停与安全停止

**在任何异常情况下，立即执行急停：**

```python
# 方法 1：断开通信（推荐）
for motor in motors.values():
    motor.disconnect()

# 方法 2：如果使用 JoyconSDK，可使用紧急停止
# sdk.joycon.emergency_stop()
```

**建议在代码中添加异常处理：**

```python
import sys

try:
    sdk.motion.move_joints([0, 90, 0, 0, 0, 0], duration=2.0)
except KeyboardInterrupt:
    print("\n检测到 Ctrl+C，执行急停...")
    for motor in motors.values():
        motor.disconnect()
    sys.exit(0)
except Exception as e:
    print(f"发生错误：{e}，执行急停...")
    for motor in motors.values():
        motor.disconnect()
    raise
```

---

## 🟢 视觉抓取安全

### 6. 视觉抓取前的准备

**视觉抓取涉及自动运动，风险更高，必须做好以下准备：**

#### 相机标定

- **未标定或标定不准确的相机会导致抓取位置错误**
- 首次使用视觉功能前，必须完成手眼标定
- 标定文件：`config/calibration_parameter.json`

```python
# 检查标定文件是否存在
import os
calib_file = "config/calibration_parameter.json"
if not os.path.exists(calib_file):
    print("⚠️  警告：未找到标定文件，视觉抓取可能不准确！")
    print("请先完成手眼标定再使用视觉功能")
else:
    print("✅ 标定文件已找到")
```

#### 抓取参数检查

```python
# 设置合理的抓取参数
sdk.vision.set_grasp_params(
    grasp_height=50,        # 抓取高度（mm），不要设置过低，避免碰撞桌面
    approach_height=100,    # 接近高度（mm），给足够的安全间隙
    tcp_offset=[0, 0, 120], # 工具中心点偏移（mm），根据夹爪长度调整
    retreat_height=150      # 抓取后抬升高度（mm）
)
```

#### 测试流程

1. **先测试单次点击**：手动点击一个已知位置，观察机械臂是否运动到正确位置
2. **逐步降低高度**：从安全高度开始，逐步降低 `grasp_height`
3. **准备急停**：整个测试过程中手放在急停按钮附近

---

## 🔵 自然语言控制安全

### 7. 自然语言控制的限制

**自然语言控制依赖 AI 解析，存在不确定性：**

- ✅ **推荐用于**：简单明确的指令（"回到初始位置"、"抬起大臂"）
- ❌ **不推荐用于**：高精度任务、安全关键场景

**使用建议：**

```python
# 方法 1：先在仿真中测试
sdk.digital_twin.start_simulation()  # 启动仿真
result = sdk.embodied.run_nl_instruction("机械臂向上移动 100mm")
# 观察仿真结果，确认无误后再在真实机械臂上执行

# 方法 2：先检查执行结果
result = sdk.embodied.run_nl_instruction("机械臂回到初始位置")
if not result.get("execution_result", {}).get("success"):
    print("指令执行失败，请检查日志")
```

---

## 📋 日常使用检查清单

每次使用前，按以下清单检查：

- [ ] 确认 Python 版本为 3.12+
- [ ] 清空机械臂工作区域
- [ ] 确认回零参数正确
- [ ] 检查各关节能够自由活动（无卡死）
- [ ] 确认电机温度正常（< 60°C）
- [ ] 准备好急停措施
- [ ] 首次运动使用低速测试
- [ ] 检查电源供电稳定

---

## 🆘 异常情况处理

| 异常情况 | 应对措施 |
|---|---|
| 机械臂运动方向错误 | 立即急停，修改 `motor_config.json` 中的 `direction` 参数 |
| 电机发出异响 | 立即断电，检查是否有机械卡死或干涉 |
| 电机过热（> 70°C） | 停止使用，等待冷却，检查负载是否过大 |
| 堵转保护触发 | 检查是否有障碍物，降低速度/加速度参数 |
| 视觉抓取位置偏差大 | 重新标定相机，检查标定文件 |
| 通信超时频繁 | 检查 CAN 总线连接，降低通信频率 |

---

## 📞 技术支持

如遇到本文档未涵盖的安全问题，请立即停止使用并联系技术支持。

**记住：安全永远是第一位的！** 🛡️

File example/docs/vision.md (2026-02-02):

# VisualGraspSDK & FollowGraspSDK - 视觉抓取与跟随

**对应源码：** `Embodied_SDK/visual_grasp.py`

## 概述

视觉模块提供两个 SDK：
- **VisualGraspSDK**: 基础视觉抓取（像素点抓取、框选抓取）
- **FollowGraspSDK**: 视觉跟随（目标检测跟随、手动框选跟踪）

## 前置条件

### 硬件要求
- USB 摄像头或工业相机
- 相机已正确连接并可被系统识别

### 软件要求
- ⚠️ **必需**：已完成相机标定（`config/calibration_parameter.json`）
- 对于目标检测跟随：需要 YOLO 模型（`config/yolov8n.onnx`）

---

## VisualGraspSDK - 基础视觉抓取

### 模块入口

```python
from Embodied_SDK import HorizonArmSDK

sdk = HorizonArmSDK(motors=motors, camera_id=0)
vision = sdk.vision  # 获取 VisualGraspSDK 实例
```

### 核心接口

#### 1. 设置抓取参数

##### `set_grasp_params(grasp_height=50, approach_height=100, tcp_offset=None, retreat_height=150, grasp_orientation=None)`

**参数：**

| 参数 | 默认值 | 说明 |
|---|---|---|
| `grasp_height` | 50 | 抓取高度（mm），相对于桌面 |
| `approach_height` | 100 | 接近高度（mm），抓取前的安全高度 |
| `tcp_offset` | `[0,0,120]` | 工具中心点偏移 [x,y,z]（mm） |
| `retreat_height` | 150 | 抓取后抬升高度（mm） |
| `grasp_orientation` | `[0,0,180]` | 抓取姿态 [yaw,pitch,roll]（度） |

**⚠️ 注意：**
- `grasp_height` 不要设置过低，避免碰撞桌面
- `tcp_offset` 需根据夹爪实际长度调整
- 首次使用建议从较高的 `grasp_height`（如 100mm）开始测试

**示例：**
```python
vision.set_grasp_params(
    grasp_height=80,
    approach_height=150,
    tcp_offset=[0, 0, 120],
    retreat_height=200
)
```

---

#### 2. 像素点抓取

##### `grasp_at_pixel(u, v) -> bool`

根据像素坐标抓取目标。

**参数：**
- `u, v`: 像素坐标

**使用场景：**
- Web/GUI 用户点击抓取
- ROS 节点接收点击坐标
- 已知目标的像素位置

**示例：**
```python
import cv2

cap = cv2.VideoCapture(0)
ret, frame = cap.read()

if ret:
    h, w = frame.shape[:2]
    center_u, center_v = w // 2, h // 2
    success = vision.grasp_at_pixel(center_u, center_v)
```

---

#### 3. 框选抓取

##### `grasp_at_bbox(x1, y1, x2, y2) -> bool`

抓取矩形框中心点。

**参数：**
- `x1, y1`: 左上角坐标
- `x2, y2`: 右下角坐标

**使用场景：**
- 结合目标检测（YOLO/Faster R-CNN）
- 用户框选目标区域

**示例：**
```python
from ultralytics import YOLO

model = YOLO("yolov8n.pt")
cap = cv2.VideoCapture(0)

ret, frame = cap.read()
results = model(frame)

for box in results[0].boxes:
    x1, y1, x2, y2 = box.xyxy[0].cpu().numpy()
    if float(box.conf[0]) > 0.5:
        vision.grasp_at_bbox(int(x1), int(y1), int(x2), int(y2))
        break
```

---

## FollowGraspSDK - 视觉跟随

### 模块入口

```python
sdk = HorizonArmSDK(motors=motors, camera_id=0)
follow = sdk.follow  # 获取 FollowGraspSDK 实例
```

### 核心接口

#### 1. 配置跟随参数

##### `configure_follow(target_class=None, confidence_threshold=0.5, control_frequency=10, ...)`

**参数：**
- `target_class`: 目标类别（如 "person", "cup"）
- `confidence_threshold`: 检测置信度阈值
- `control_frequency`: 控制频率（Hz）

**示例：**
```python
follow.configure_follow(
    target_class="cup",
    confidence_threshold=0.6,
    control_frequency=10
)
```

---

#### 2. 单步跟随（推荐）

##### `follow_step(frame) -> bool`

执行一次跟随步骤。

**参数：**
- `frame`: 当前帧图像（numpy 数组）

**使用场景：**
- 自定义采图循环
- ROS 节点订阅图像话题
- Web 后端接收视频流

**示例：**
```python
import cv2

cap = cv2.VideoCapture(0)
follow.configure_follow(target_class="person")

while True:
    ret, frame = cap.read()
    if not ret:
        break
    
    success = follow.follow_step(frame)
    
    if success:
        print("正在跟随目标")
    
    cv2.imshow("Follow", frame)
    if cv2.waitKey(1) & 0xFF == ord('q'):
        break
```

---

#### 3. 后台循环跟随

##### `start_follow_grasp(...)` / `stop_follow_grasp()` / `is_following()`

启动后台跟随线程。

**示例：**
```python
# 启动
follow.start_follow_grasp(target_class="cup", camera_id=0)

# 检查状态
while follow.is_following():
    time.sleep(0.1)

# 停止
follow.stop_follow_grasp()
```

---

#### 4. 手动框选跟踪

##### `init_manual_target(frame0, x1, y1, x2, y2) -> bool`

手动框选目标并初始化跟踪器。

**使用场景：**
- 用户手动框选目标
- 跟踪特定物体（无需目标检测模型）

**示例：**
```python
import cv2

cap = cv2.VideoCapture(0)
ret, frame = cap.read()

# 让用户框选目标
bbox = cv2.selectROI("Select Target", frame, False)
x, y, w, h = bbox

# 初始化跟踪器
follow.init_manual_target(frame, x, y, x+w, y+h)

# 开始跟随
while True:
    ret, frame = cap.read()
    if not ret:
        break
    
    success = follow.follow_step(frame)
    if not success:
        break
    
    cv2.imshow("Following", frame)
    if cv2.waitKey(1) & 0xFF == ord('q'):
        break
```

---

## 配置文件

### calibration_parameter.json（必需）

相机标定参数：

```json
{
  "camera_matrix": [[fx, 0, cx], [0, fy, cy], [0, 0, 1]],
  "dist_coeffs": [k1, k2, p1, p2, k3],
  "rotation_matrix": [...],
  "translation_vector": [...]
}
```

### motor_config.json

电机配置（减速比、方向等）。

---

## 安全建议

1. **标定检查**：
   - 首次使用前必须完成手眼标定
   - 更换相机或安装位置后需重新标定

2. **参数设置**：
   - 从较高的 `grasp_height` 开始测试
   - 逐步降低高度找到最佳抓取点

3. **测试流程**：
   - 先在已知位置测试，验证抓取精度
   - 确认无误后再用于实际场景

---

## 相关文档

- [安全须知](safety.md) - 视觉抓取安全注意事项
- [配置说明](configuration.md) - 标定文件配置
- [MotionSDK](motion.md) - 运动控制接口
- [API 详细参考](api_detailed.md) - 完整 API 说明

## 示例脚本

- **`example/test_visual_grasp.py`**  
  **用途：** 视觉抓取综合测试工具。  
  **功能：** 提供交互式菜单，测试像素点抓取、框选抓取和视觉跟随功能。

- **`example/ai_sdk_examples/simple_depth_estimation.py`**  
  **用途：** 极简深度估计演示。  
  **功能：** 展示如何用一行代码调用深度估计功能，支持从文件计算视差图和单点测距。

- **`example/ai_sdk_examples/depth_estimation_examples.py`**  
  **用途：** 交互式深度估计综合示例。  
  **功能：** 提供菜单选择，可运行“文件模式”（读取本地图片）或“内存模式”（直接处理图像数组），展示完整的深度图生成与可视化流程。

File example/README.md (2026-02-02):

# HorizonArm SDK 示例代码目录

欢迎使用 HorizonArm SDK！本目录提供完整的示例代码和开发者工具。

## 📚 首次使用必读

### 🎯 不知道从哪里开始？

1. **了解SDK** → 📖 **[SDK完全介绍.md](SDK完全介绍.md)** ⭐ **强烈推荐先看这个！**
   - SDK架构和模块总览
   - 各模块功能详解和API示例
   - 核心概念和设计理念
   - 典型应用流程
   
2. **快速上手** → 🚀 **`quickstart_guide.py`** (5分钟体验)
   - 连接电机
   - 读取状态
   - 执行运动
   
3. **深入学习** → 📚 按照下方的学习路径逐步学习

---

## 📂 目录结构

```
example/
├── quickstart_guide.py              ⭐ 【从这里开始】5分钟快速入门
├── test_gripper_torque.py           - 夹爪（电机ID=7）力矩模式测试（clamp/open）
│
├── control_sdk_examples/            📚 Control SDK 功能示例
│   ├── README.md                    - 学习路径指南
│   ├── motor_usage_example.py       - 单电机完全指南
│   ├── visual_grasp_example.py      - 视觉抓取功能
│   ├── joycon_control_example.py    - 手柄遥操作
│   ├── multi_motor_sync_example.py  - 多电机同步（简化版）
│   ├── io_control_example.py        - IO控制
│   └── digital_twin_example.py      - MuJoCo仿真（可选，教学版最短示例）
│
├── ai_sdk_examples/                 🧠 AI SDK 功能示例
│   ├── config_example.py            - 配置管理
│   ├── LLM_usage.py                 - 大语言模型
│   ├── asr_usage_example.py         - 语音识别
│   ├── tts_usage_example.py         - 语音合成
│   ├── multimodal_usage_example.py  - 多模态AI
│   ├── smart_chat_example.py        - 智能对话
│   └── ...
│
├── developer_tools/                 🛠️ 开发者调试工具
│   ├── README.md                    - 工具说明
│   ├── joycon_sensor_display.py     - Joy-Con传感器监控
│   ├── mujoco_slider_viewer.py      - MuJoCo 底层滑块调试工具（可选）
│   └── ...
│
└── (旧示例 - 保留供参考)
    ├── sdk_quickstart.py            - 完整机械臂控制（保留）
    ├── test_interactive.py          - 完整单电机测试（保留）
    ├── test_multi_motor_sync.py     - 完整多机同步（保留）
    └── ...
```

## 🚀 快速开始

## 📦 依赖安装说明（与 requirements.txt 对应）

本仓库根目录的 `requirements.txt` 已按“开源版默认必装 / 可选功能按需安装”做了分组：

- **开源版默认必装**：能跑通机械臂控制（UCP/串口）与视觉示例的核心依赖
- **可选依赖**：AI / 语音 / Joy-Con / MuJoCo / 可视化等示例才需要（在 `requirements.txt` 里取消注释对应分组即可）

### 第一次使用？从这里开始！

```bash
cd example
python quickstart_guide.py
```

5分钟内您将学会：
- ✅ 连接一台电机
- ✅ 读取电机状态
- ✅ 执行简单运动
- ✅ 了解SDK核心概念

### 已经完成快速入门？继续学习

根据您的需求选择：

#### 🎯 我要学习机械臂控制
```bash
cd control_sdk_examples
# 1. 单电机控制
python motor_usage_example.py
# 2. 多电机同步（推荐）
python multi_motor_sync_example.py
```

#### 👁️ 我要使用视觉功能
```bash
cd control_sdk_examples
python visual_grasp_example.py
```

#### 🎮 我要用手柄控制
```bash
cd control_sdk_examples
python joycon_control_example.py
```

#### 🧠 我要使用AI功能
```bash
cd ai_sdk_examples
python config_example.py        # 先了解配置
python LLM_usage.py             # 再使用AI功能
```

## 📊 示例对比：简化版 vs 完整版

| 功能 | 简化教学版 | 完整专业版 |
|---|---|---|
| **单电机控制** | `control_sdk_examples/motor_usage_example.py`<br>7个核心功能，带详细说明 | `test_interactive.py`<br>40+功能，所有API覆盖 |
| **多机同步** | `control_sdk_examples/multi_motor_sync_example.py`<br>3个核心同步模式 | `test_multi_motor_sync.py`<br>26+功能，包含诊断工具 |
| **手柄控制** | `control_sdk_examples/joycon_control_example.py`<br>分4级学习，整合3个原示例 | `test_joycon_*.py`<br>3个独立文件 |

💡 **建议：**
- 🎓 **学习阶段**：使用 `control_sdk_examples/` 下的简化版
- 🔧 **开发阶段**：参考完整版的高级功能
- 🐛 **调试阶段**：使用 `developer_tools/` 下的专业工具

## 🎯 学习路径推荐

### 路径1：机械臂控制工程师
```
quickstart_guide.py
    ↓
motor_usage_example.py (30min)
    ↓
sdk_quickstart.py (30min)
    ↓
multi_motor_sync_example.py (20min)
    ↓
test_interactive.py (参考完整API)
```

### 路径2：视觉应用开发者
```
quickstart_guide.py
    ↓
motor_usage_example.py (基础)
    ↓
visual_grasp_example.py (45min)
    ↓
结合AI SDK: multimodal_usage_example.py
```

### 路径3：人机交互开发者
```
quickstart_guide.py
    ↓
joycon_control_example.py (40min)
    ↓
io_control_example.py (20min)
    ↓
结合AI SDK: smart_chat_example.py
```

### 路径4：AI集成开发者
```
ai_sdk_examples/config_example.py
    ↓
LLM_usage.py
    ↓
multimodal_usage_example.py
    ↓
smart_multimodal_voice_chat_demo.py
    ↓
结合Control SDK完成具身智能
```

## 🔑 关键概念

### Control SDK核心
- **电机控制**: 速度/位置/力矩三种模式
- **运动学**: 关节空间 vs 笛卡尔空间
- **同步控制**: Pre-load → Trigger → Execute
- **IO控制**: DI读取 + DO输出
- **数字孪生**: MuJoCo仿真验证（可选，非 UI）

### AI SDK核心
- **配置管理**: YAML配置 + 运行时修改
- **大语言模型**: LLM接口统一封装
- **多模态**: 视觉 + 语音 + 文本整合
- **具身智能**: AI + 机械臂深度结合

## ⚠️ 重要说明

### 关于SDK版本
本开发包使用 `Horizon_Core/` 封装库，提供稳定的API接口。所有示例代码均基于此版本编写，可直接用于您的项目开发。

### 关于代码集成
本SDK专注于提供机械臂控制和AI功能的核心接口。示例代码展示了完整的API调用方法，您可以：
- 直接复制示例代码到项目中
- 集成到自己的应用架构
- 开发自定义的用户界面
- 实现特定的业务逻辑

## 📖 文档资源

- **SDK完全介绍**: `SDK完全介绍.md` ⭐ **必读！包含所有模块的详细说明**
- **API参考**: `docs/api_reference.md`
- **故障排除**: `docs/troubleshooting.md`
- **配置说明**: `docs/configuration.md`
- **最佳实践**: `docs/best_practices.md`

## 🆘 获取帮助

遇到问题？按以下顺序排查：

1. ✅ 检查 `docs/troubleshooting.md`
2. ✅ 运行对应的系统自检（如 `visual_grasp_example.py` 的自检功能）
3. ✅ 参考完整版示例的详细API调用
4. ✅ 使用 `developer_tools/` 下的诊断工具
5. ✅ 联系技术支持

## 🎓 从示例到生产

示例代码的设计理念：
- **可复制**: 代码片段可直接复制到您的项目
- **可扩展**: 提供了清晰的扩展点
- **可学习**: 每个功能都有详细注释和说明

从示例到生产代码的建议：
1. 先运行示例，理解功能
2. 复制核心代码片段
3. 根据需求调整参数
4. 添加错误处理和日志
5. 集成到您的应用架构中

---

**版本**: 1.4  
**更新日期**: 2024  
**维护**: HorizonArm Team  

祝您开发顺利！🚀

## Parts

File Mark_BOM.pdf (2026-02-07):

# 桌面型六轴具身智能机械臂

### 型号：Mark

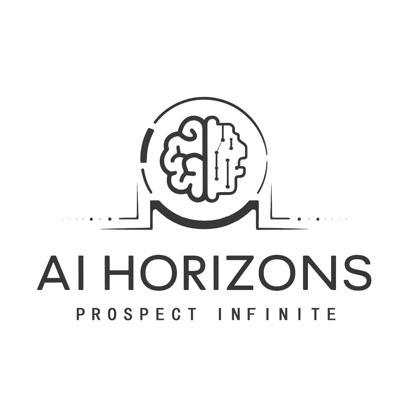
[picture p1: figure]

日期：2026/2/1

保密等级：公开

# 官方淘宝链接 (https://m.tb.cn/h.7HtA8e9tgs4OG3s)

# 1. 结构部分

序 号 | 物料 名称 | 规格/型 号描述 | 数 量 | 备注 | 照片
1 | 底座 2 | ABS-GF 3D 打印 | 1 | 层墙数： 4 填充密度： 50% 填充类型： 三角形

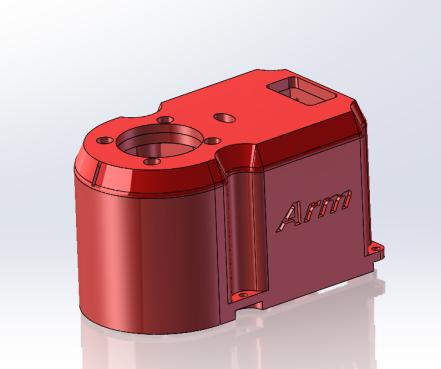
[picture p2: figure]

2 | 底座 1 | ABS-GF 3D 打印 | 1 | 层墙数： 4 填充密度： 50% 填充类型： 三角形
3 | 关节 2 | ABS-GF 3D 打印 | 1 | 层墙数： 4 填充密度： 50% 填充类型： 三角形 （圆柱需要 100%填充密 度）

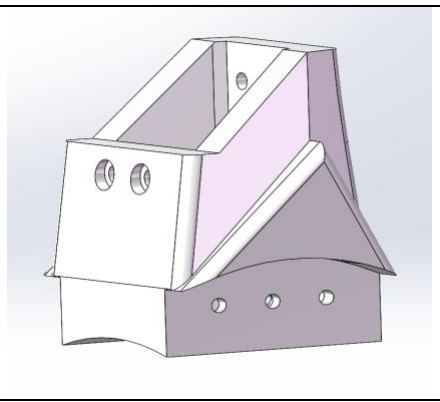
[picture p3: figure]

4 | 大臂 连接 1 | ABS-GF 3D 打印 | 1 | 层墙数： 4 填充密度： 50% 填充类型： 三角形
5 | 关节 2 法 兰支 撑 | ABS-GF 3D 打印 | 1 | 层墙数： 4 填充密度： 50% 填充类型： 三角形

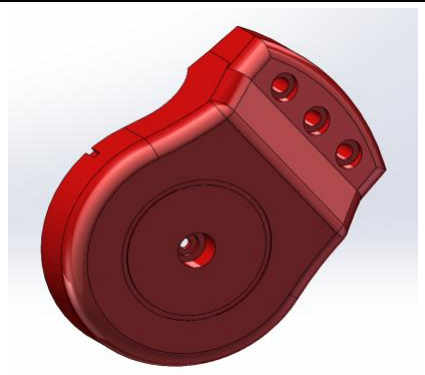
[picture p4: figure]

6 | 关节 2 同 步后 盖支 撑 | ABS-GF 3D 打印 | 1 | 层墙数： 4 填充密度： 50% 填充类型： 三角形
7 | 关节 2 同 步后 盖 | ABS-GF 3D 打印 | 1 | 层墙数： 4 填充密度： 50% 填充类型： 三角形

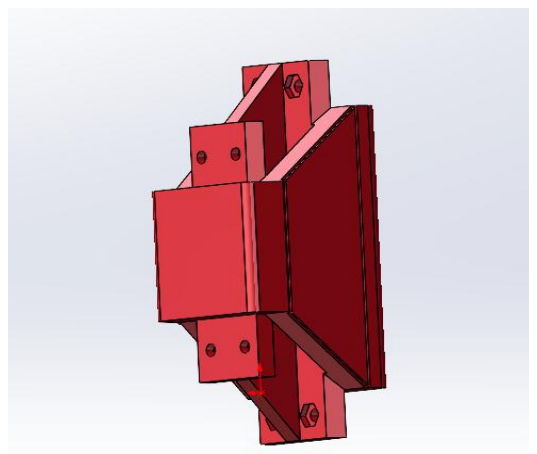
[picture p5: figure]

8 | 大臂 杆 | ABS-GF 3D 打印 | 1 | 层墙数： 4 填充密度： 50% 填充类型： 三角形
9 | 关节 3 | ABS-GF 3D 打印 | 1 | 层墙数： 4 填充密度： 50% 填充类型： 三角形 （圆柱需要 100%填充密 度）

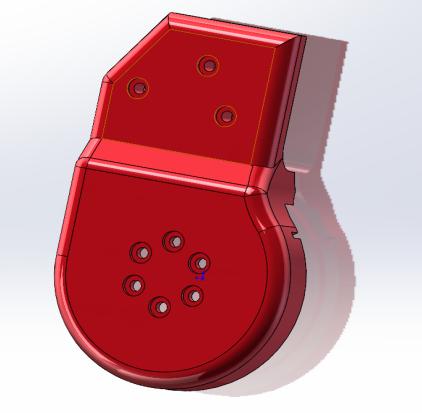
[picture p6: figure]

10 | 关节 3 法 兰支 撑 | ABS-GF 3D 打印 | 1 | 层墙数： 4 填充密度： 50% 填充类型： 三角形
11 | 关节 3 同 步支 撑 | ABS-GF 3D 打印 | 1 | 层墙数： 4 填充密度： 50% 填充类型： 三角形

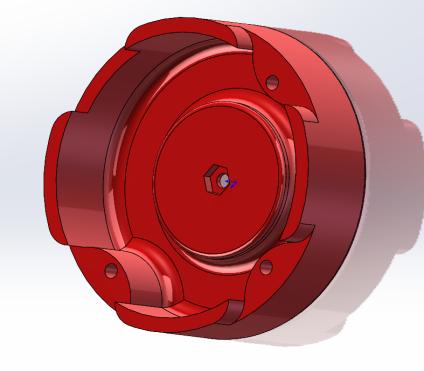
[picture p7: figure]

12 | 关节 3 同 步后 盖 | ABS-GF 3D 打印 | 1 | 层墙数： 4 填充密度： 50% 填充类型： 三角形
13 | 小臂 关节 连接 | ABS-GF 3D 打印 | 1 | 层墙数： 4 填充密度： 50% 填充类型： 三角形

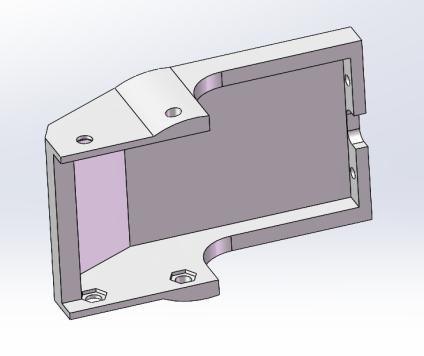
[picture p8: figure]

14 | 小臂 关节 盖板 | ABS-GF 3D 打印 | 1 | 层墙数： 4 填充密度： 50% 填充类型： 三角形
15 | 小臂 长 | ABS-GF 3D 打印 | 1 | 层墙数： 4 填充密度： 50% 填充类型： 三角形


16 | 小臂 测盖 1 | ABS-GF 3D 打印 | 1 | 层墙数： 4 填充密度： 50% 填充类型： 三角形
17 | 小臂 侧盖 2 | ABS-GF 3D 打印 | 1 | 层墙数： 4 填充密度： 50% 填充类型： 三角形


18 | 6 关 节模 块 | ABS-GF 3D 打印 | 1 | 层墙数： 4 填充密度： 50% 填充类型： 三角形
19 | 6 关 节模 块盖 板 | ABS-GF 3D 打印 | 1 | 层墙数： 4 填充密度： 50% 填充类型： 三角形


20 | 42 斜坡 后盖 | ABS-GF 3D 打印 | 1 | 层墙数： 4 填充密度： 100% 填充类型： 三角形
21 | 轴承 支撑 | ABS-GF 3D 打印 | 3 | 层墙数： 4 填充密度： 100% 填充类型： 三角形


22 | 谐波 法兰 | 铝 CNC 加 工 | 5 | 需要攻牙

# 2. 电子电气部分

序 号 | 物料名称 | 规格/型号描 述 | 数 量 | 备注 | 照片
1 | OmniCAN 控制板 | Can | 1 | 由官 方提 供


2 | 伺服关节 模组 | | 6 | 由官 方提 供
4 | 电源适配 器 | 24V3A | 1


5 | DC 电源 插座 | DC5.5 | 1
6 | USB-Hub | 4 口带辅助供 电 | 1 | 由官 方提 供


7 | 免焊接 DC 母头 | DC5.5 | 1
8 | XH2.54 对 插端子线 | 4P | 1 | 公母 各一 个


9 | Usb 转 type c | 10cm 长 | 1 | 需要 USB 向右 款

# 3. 标准件与辅件

序 号 | 物料 名称 | 规格/型号描 述 | 数 量 | 备注 | 照片
1 | 轴承 | 内径： 45mm 外径： 55mm | 3


2 | 轴承 | 内径： 20mm 外径： 30mm | 2
3 | 轴承 | 623ZZ | 2


4 | 同步 轮 | GT2 同步轮 | 1
5 | 同步 轮 | B5-W6 | 1


6 | 同步 带 | GT2 同步带 | 1
7 | D 型 轴 | 长：30mm 轴径：5mm | 1


8 | 编制 网 | 内径： 10mm | 1 | 需要 1 米
9 | M3 螺丝 | 8mm： 10mm： 12mm： 15mm： 30mm： 45mm： 50mm： | *18 *8 *14 *4 *7 *3 *2 | 发货一 般多配 几个


10 | M4 螺丝 | 8mm： 10mm： 12mm： 14mm： 16mm： 18mm： 22mm： | *4 *6 *2 *16 *2 *4 *6 | 发货一 般多配 几个
11 | 铁质 垫片 | M3*7*0.5 M4*7*0.5 | *40 *56 | 发货一 般多配 几个


12 | 螺母 | M3 M4 | *40 *56 | 需要薄 螺母

注：

数据采集器跟 reSpeaker 需要到指导店铺购买


1 | 采集器 | 淘宝 (https://item.taobao.com/item.htm?abbucket=16&id=906216210985)


2 | reSpeaker | 淘宝 (https://item.taobao.com/item.htm?abbucket=1&id=548667422899&ns=1&skuId=5937123813574&xxc=taobaoSearch)

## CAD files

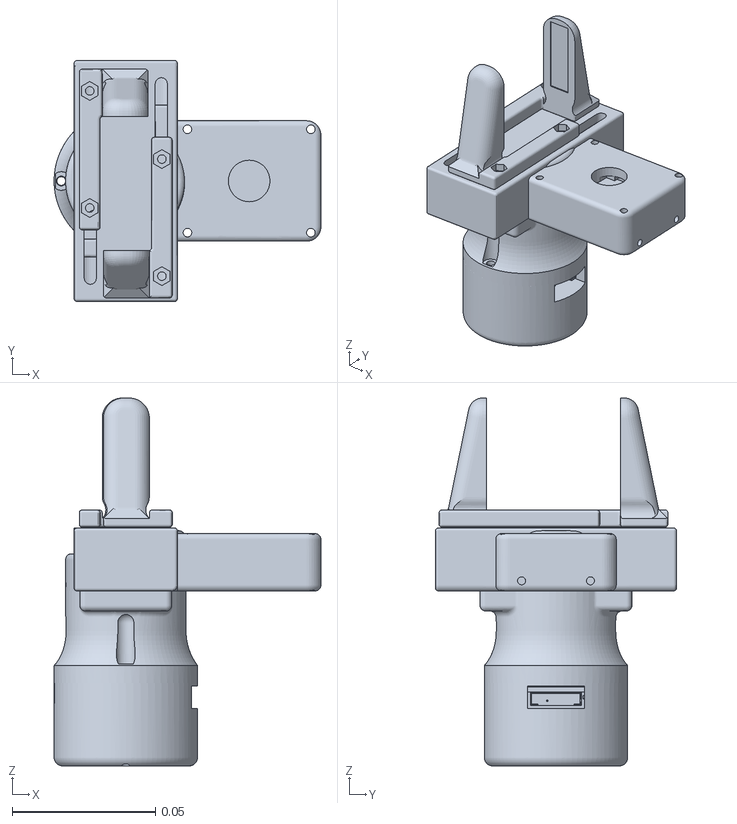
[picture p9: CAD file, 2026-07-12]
config/urdf/Link_6.STL
0.093 x 0.084 x 0.128

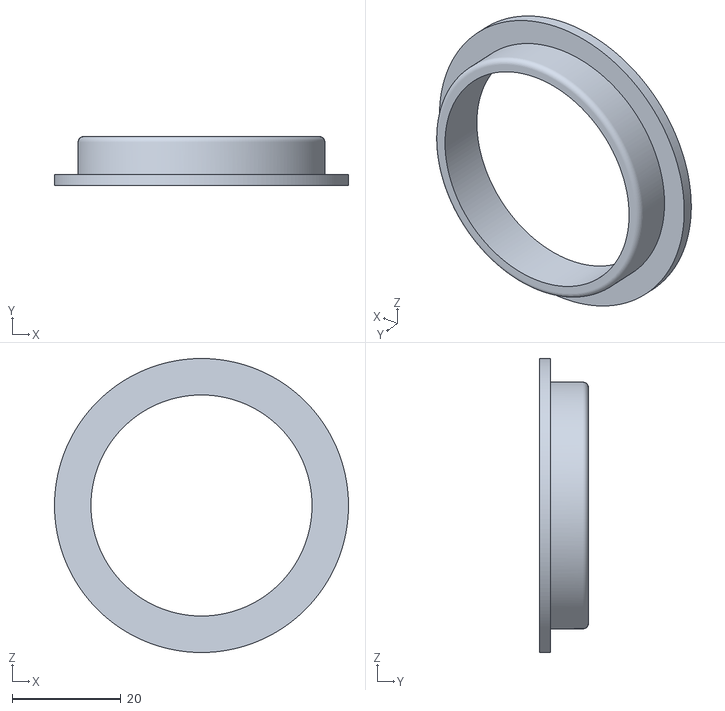
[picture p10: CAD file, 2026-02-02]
Model/轴承支撑.STL
54.0 x 9.00 x 54.0

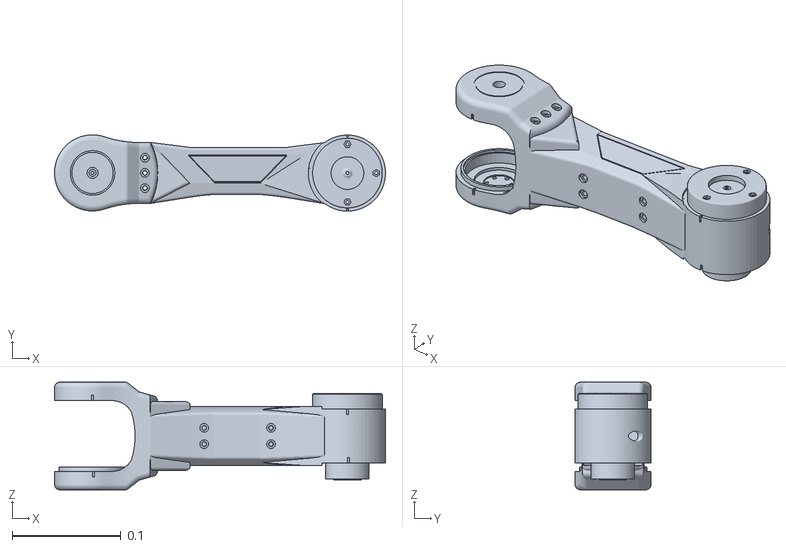
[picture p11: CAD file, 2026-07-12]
config/urdf/Link_2.STL
0.304 x 0.0702 x 0.099

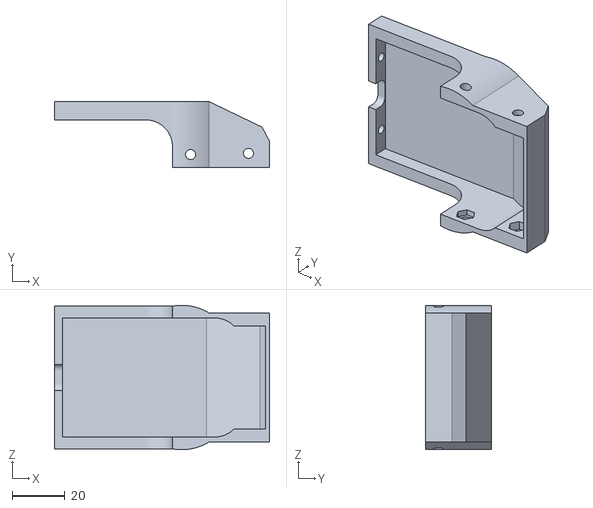
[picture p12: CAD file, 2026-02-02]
Model/小臂关节盖板.STL
81.4 x 25.0 x 54.6

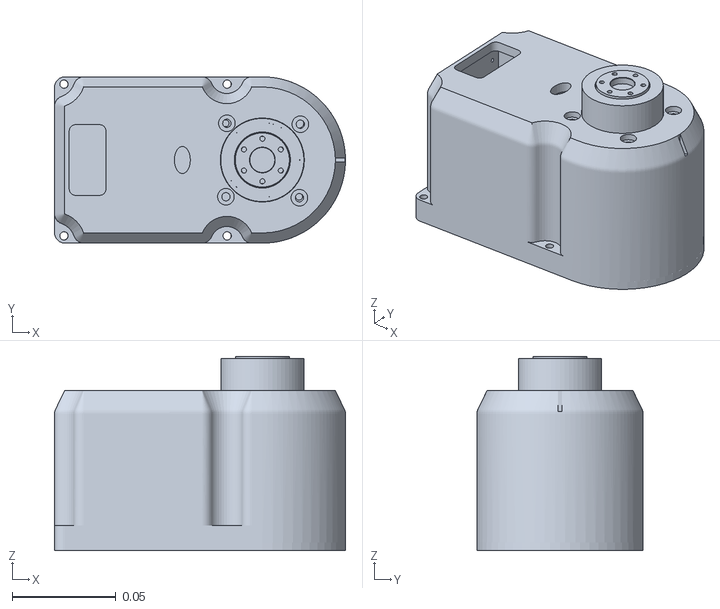
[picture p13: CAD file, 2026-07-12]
config/urdf/base_link.STL
0.14 x 0.08 x 0.0935

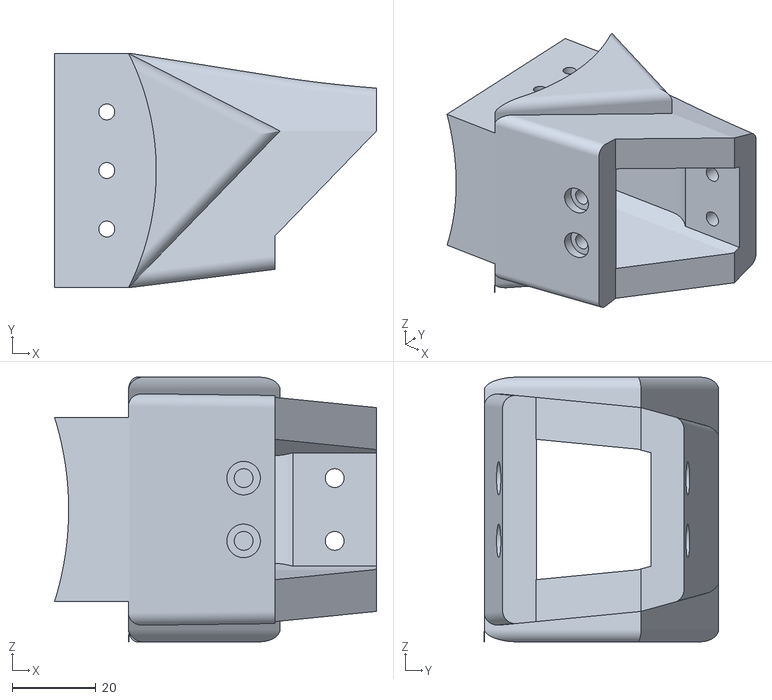
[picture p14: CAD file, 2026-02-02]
Model/大臂连接1.STL
77.0 x 56.0 x 63.3

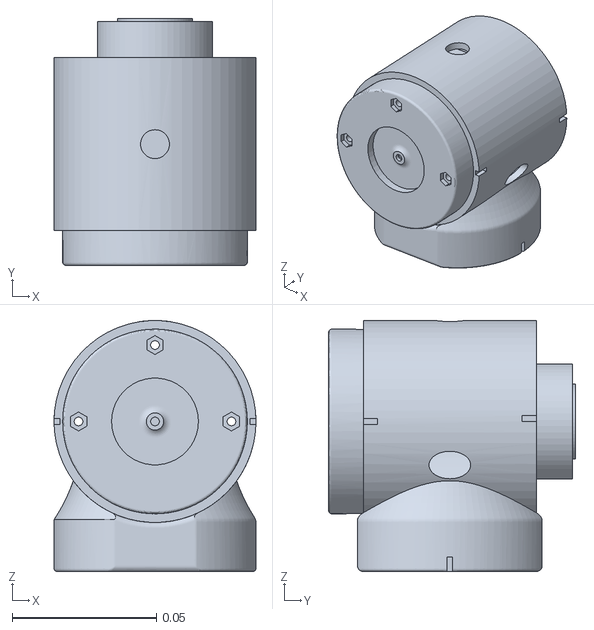
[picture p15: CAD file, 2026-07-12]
config/urdf/Link_1.STL
0.07 x 0.0855 x 0.087

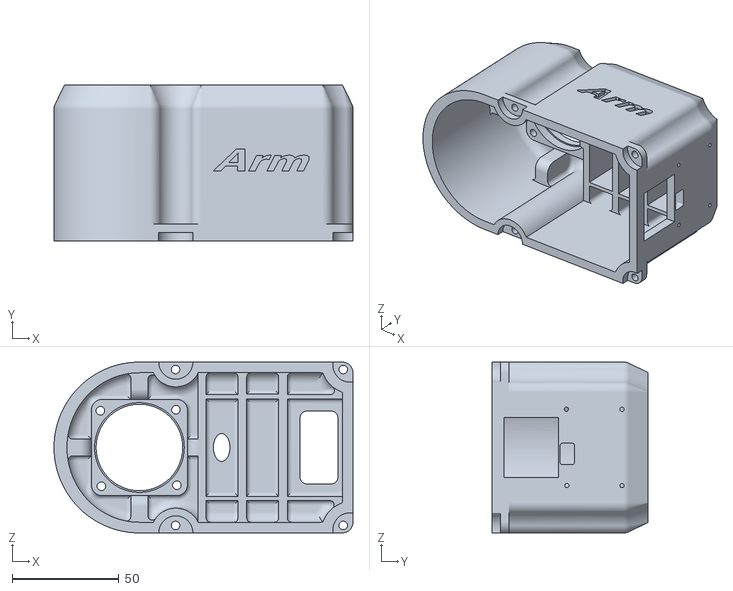
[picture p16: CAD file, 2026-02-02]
Model/底座1.STL
140.0 x 73.0 x 80.0

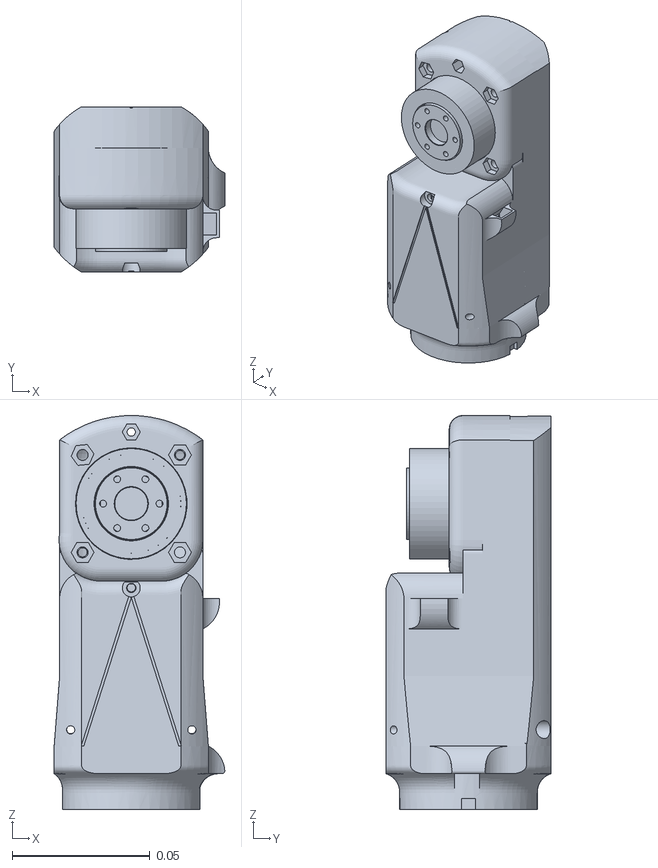
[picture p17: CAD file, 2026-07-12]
config/urdf/Link_4.STL
0.062 x 0.06 x 0.143

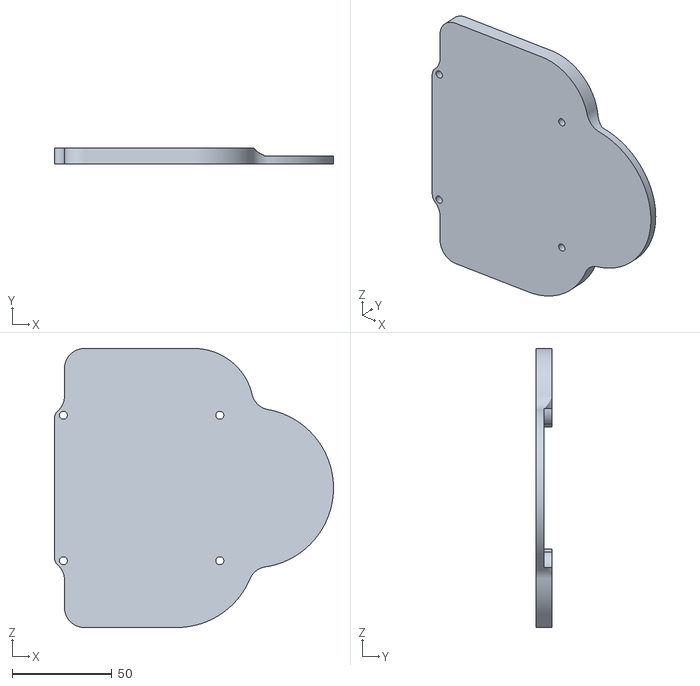
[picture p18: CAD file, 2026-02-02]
Model/底座2_大.STL
140.0 x 8.00 x 140.0

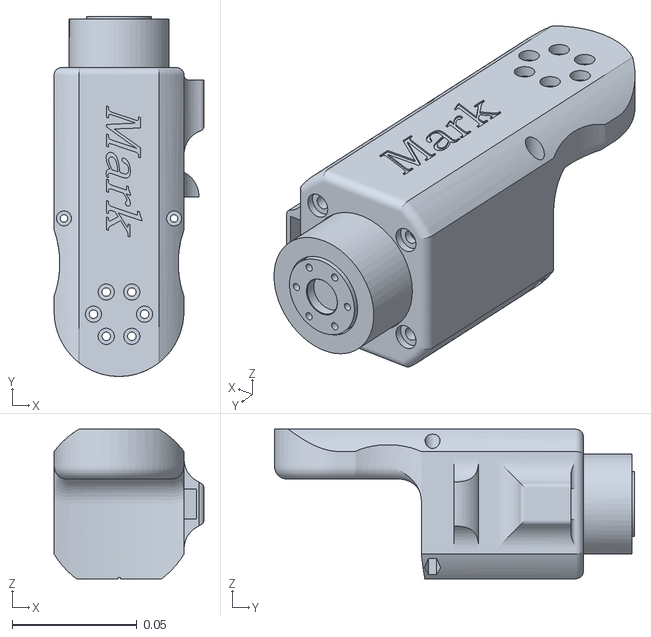
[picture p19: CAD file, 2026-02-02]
config/urdf/Link_5.STL
0.0602 x 0.144 x 0.06

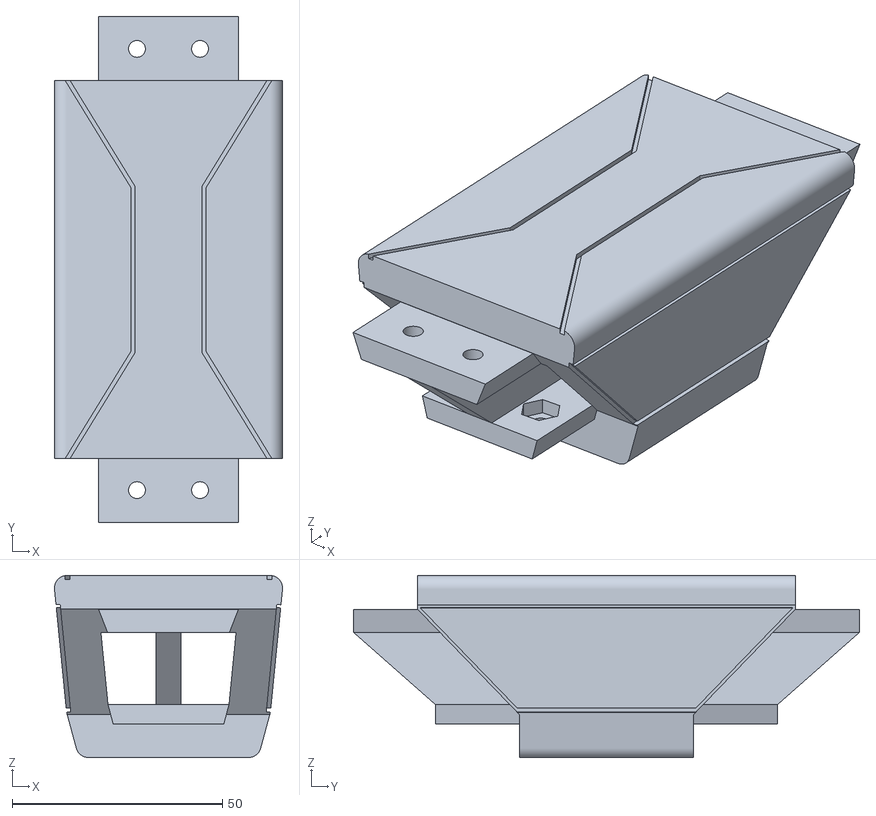
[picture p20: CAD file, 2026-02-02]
Model/大臂杆.STL
54.3 x 120.4 x 43.3

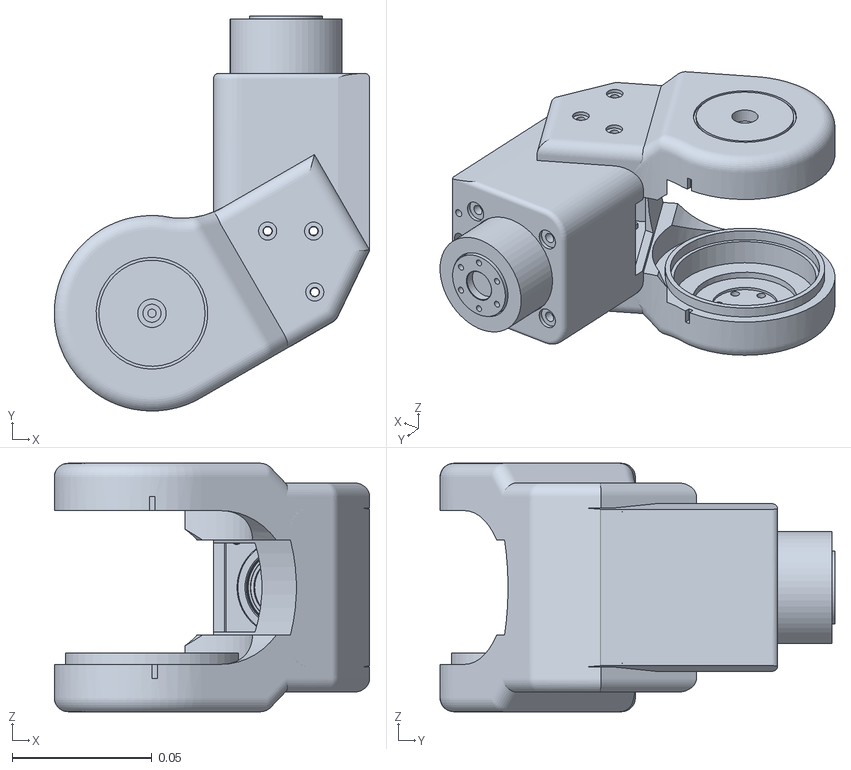
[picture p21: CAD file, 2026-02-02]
config/urdf/Link_3.STL
0.113 x 0.141 x 0.089

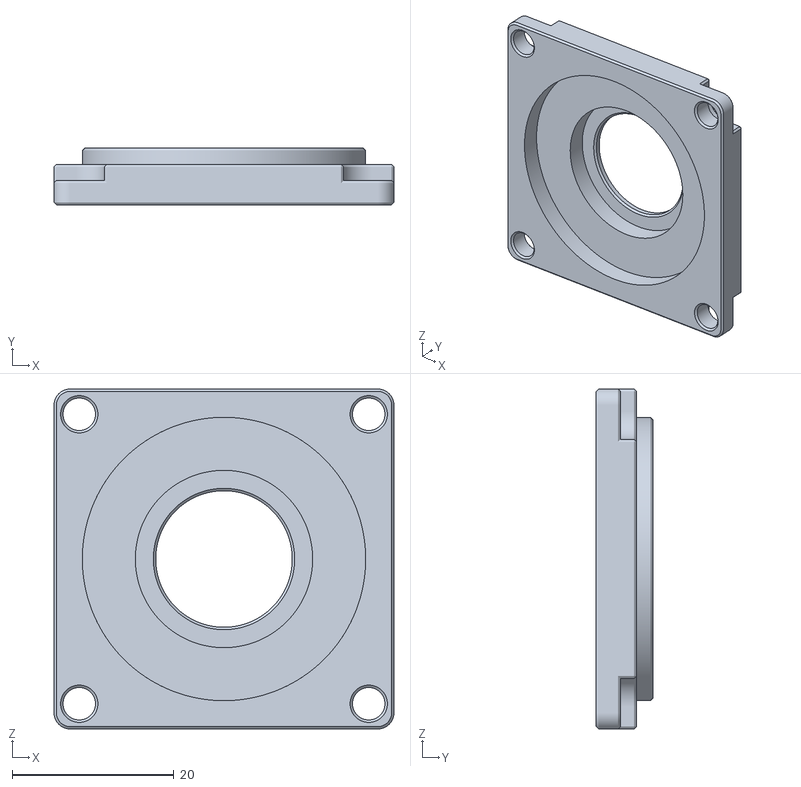
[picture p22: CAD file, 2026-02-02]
Model/42斜坡后盖.STL
42.0 x 7.00 x 42.0

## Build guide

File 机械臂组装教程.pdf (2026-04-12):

# 机械臂组装流程 （Mark）

日期：2026/1/3
保密等级：公开

相关套件购买链接 (https://item.taobao.com/item.htm?ft=t&id=1042961009564&spm=a21dvs.23580594.0.0.4fee2c1bRgX4id)

# 电机校准与谐波的安装

首先准备好装有驱动板的电机模组套件

对每一轴做好标记（贴标签）并且装上电机线
最长对应 1、2 轴
第二长对应 3、4 轴
最短的对应 5、6 轴

=========
=========
插上通讯线，注意观察驱动板上的灯的颜色，一闪一闪的绿灯为正确。

注意，如果灯的颜色不对需要需对应下表查故障

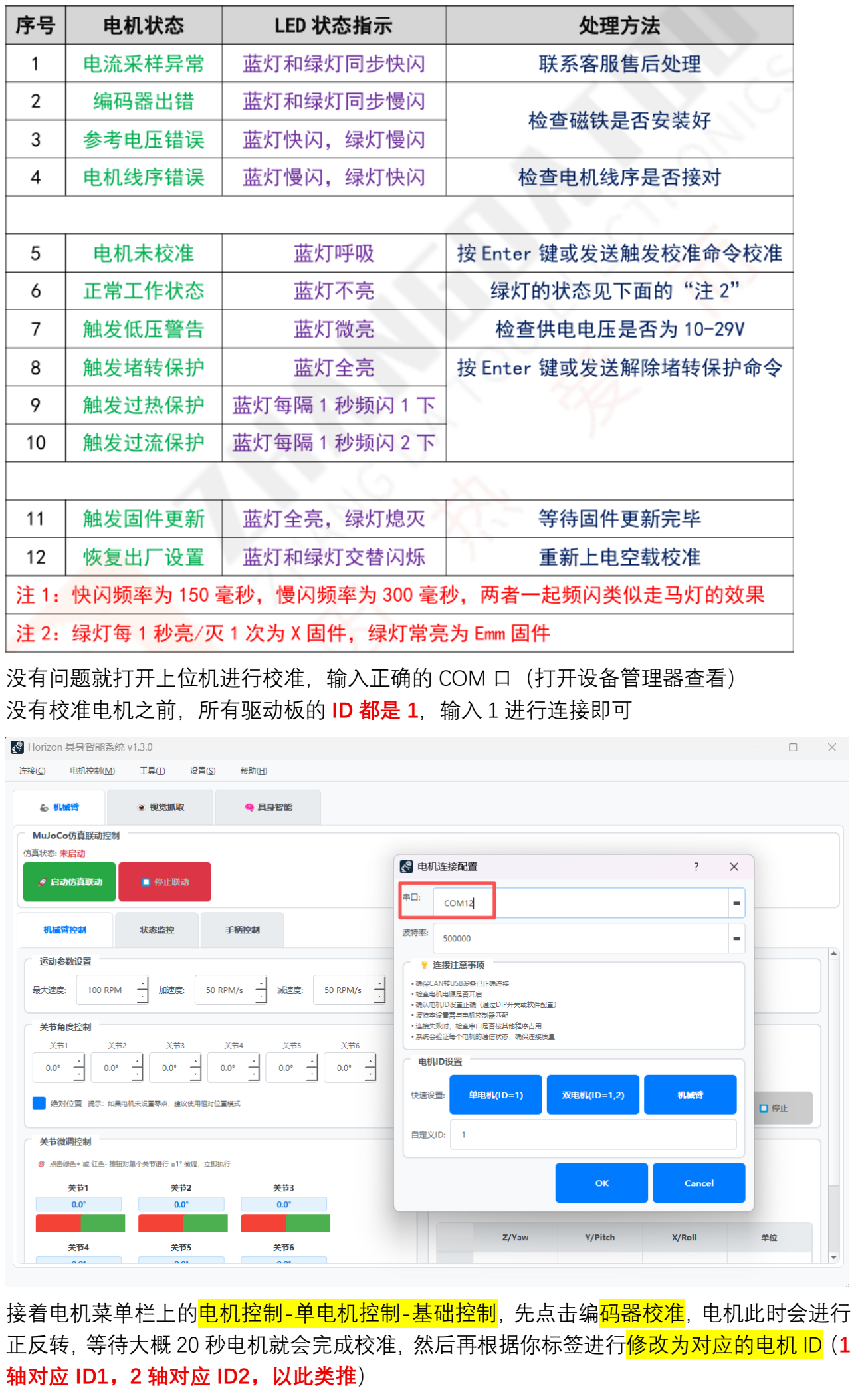
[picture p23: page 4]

没有问题就打开上位机进行校准，输入正确的 COM 口（打开设备管理器查看） 没有校准电机之前，所有驱动板的 ID 都是 1，输入 1 进行连接即可

接着电机菜单栏上的电机控制-单电机控制-基础控制，先点击编码器校准，电机此时会进行 正反转，等待大概 20 秒电机就会完成校准，然后再根据你标签进行修改为对应的电机 ID（（1 轴对应 ID1，2 轴对应 ID2，以此类推）

完成所有电机的编码器校准跟修改电机 ID 后摆放好

接下来进行谐波减速器的组装，一共有两种型号的减速器
1、2、3 轴用 11-50
4、5、6 轴用 11-30

首先为电机装上法兰，用配套的螺丝

打对角

接着装上波发生器

然后给减速器上润滑脂

给减速器装上黑色橡皮筋

然后给电机插上通讯线，接上电源跟 MoniCAN

然后需要把后盖的两个按钮去掉，放置组装过程中误触

打开上位机连接对应的 ID，打开菜单栏上的电机控制-单电机控制-运动控制-速度模式，输 入运动速度 200RPM，点击开始速度运动让电机转起来。

在电机运动的过程中把谐波减速器装上去

装成这样即可
（如果减速头安装上去后根法兰之间有间隙，需要把波发生器安装下去点）

然后需要注意的是，减速头的螺丝孔有两个大，两个小，小孔是带有螺丝牙的

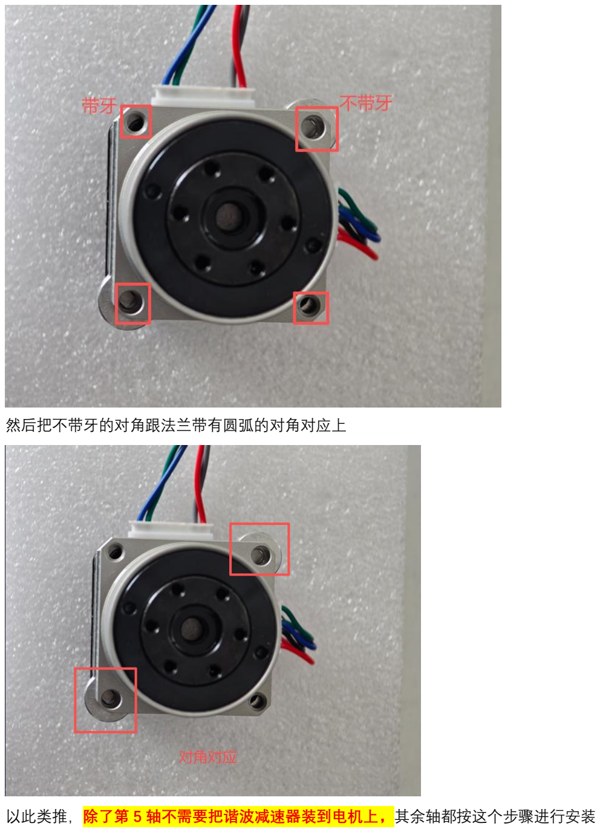
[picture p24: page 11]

然后把不带牙的对角跟法兰带有圆弧的对角对应上

以此类推，除了第 5 轴不需要把谐波减速器装到电机上，其余轴都按这个步骤进行安装

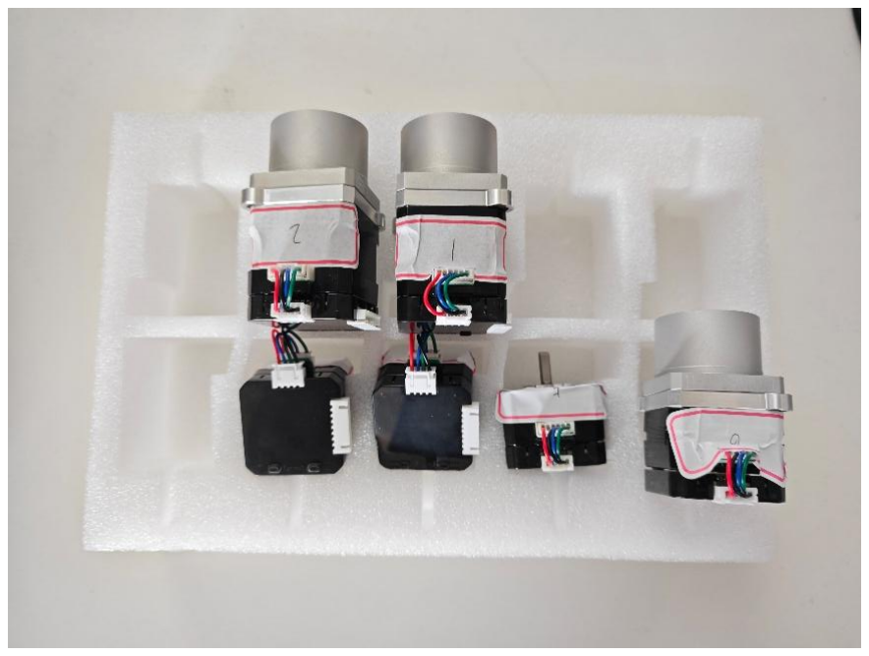
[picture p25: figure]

装机

给 1 轴电机的驱动板安装电池

组装成这样即可

按照这种朝向按照到底座上

然后要记住带圆弧边的对角位置

用两个 M4*16mm 长的螺丝，带上垫片（以后的组装都要带上垫片），安装到带有圆弧边的 对角

然后再用两个 M4*10mm 的螺丝安装到没有圆弧的对角

安装成这样即可

接下来处理通讯线

这里需要注意线的两头顺序是不对应的（右边的才是正确顺序）

首先先把 8P 接口中间的 4 根线取出来，用尖锐的东西把倒钩按进去。

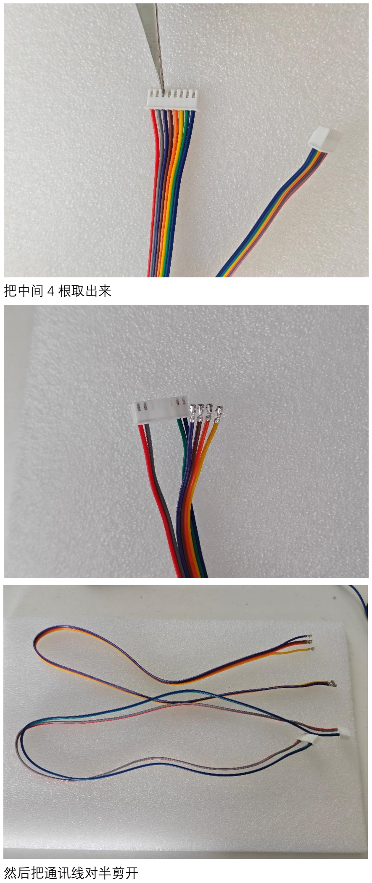
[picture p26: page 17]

把中间 4 根取出来

然后把通讯线对半剪开

刚才说的，因为两头的线序不对应，我是建议把线序都改成正确的线序，如果不改就需要自 己记住正极、负极、H、L 线的颜色。
一样用尖锐的东西把倒钩按进去取出线。

然后根据正确的顺序重新装回去，按照左边的正确线序

后续处理通讯线都用这种方法，后面几轴都会用到，需要记好 完成后拿其中一根插到一轴

按照下面的线序进行焊接
（正极）红对黄
（负极）灰对橙
（H）绿对棕
（L）蓝对紫

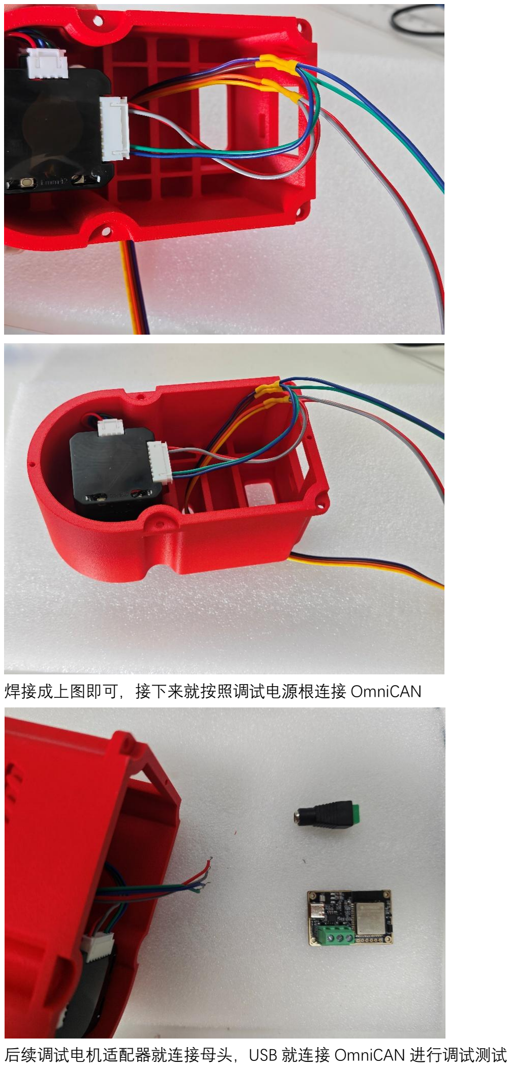
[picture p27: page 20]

焊接成上图即可，接下来就按照调试电源根连接 OmniCAN

后续调试电机适配器就连接母头，USB 就连接 OmniCAN 进行调试测试

找到这些物件

首先把 45*55*7 轴承安装到轴承支撑上

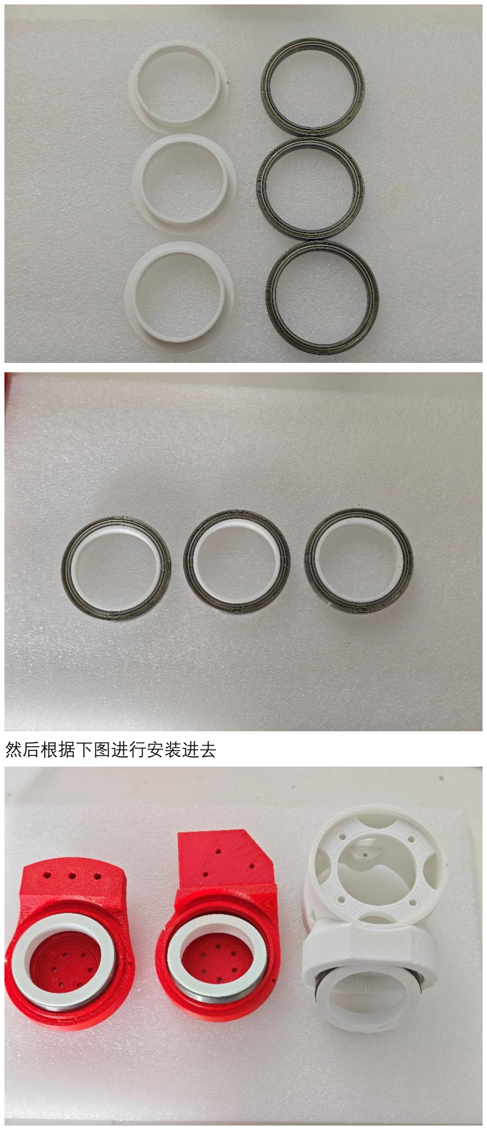
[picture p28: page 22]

然后根据下图进行安装进去

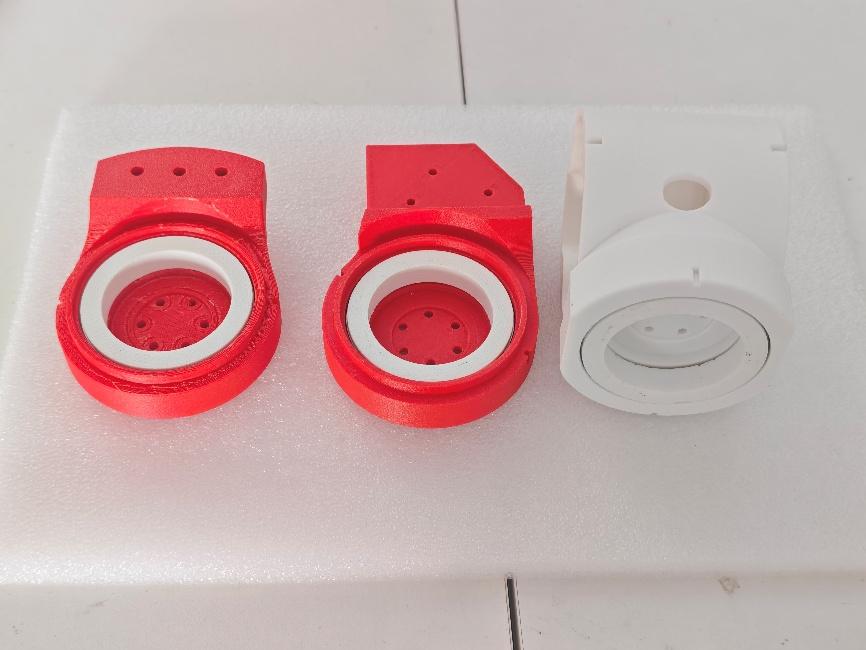
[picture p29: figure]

关节 2 根关节 3 同步后盖的安装只需要把轴承支撑跟内壁的边平行即可

然后把关节 2 安装到关节 1 的法兰上

用 6 颗 M3*12mm 的螺丝固定

接着把这 4 根通讯线保留大概 25CM 左右的长度

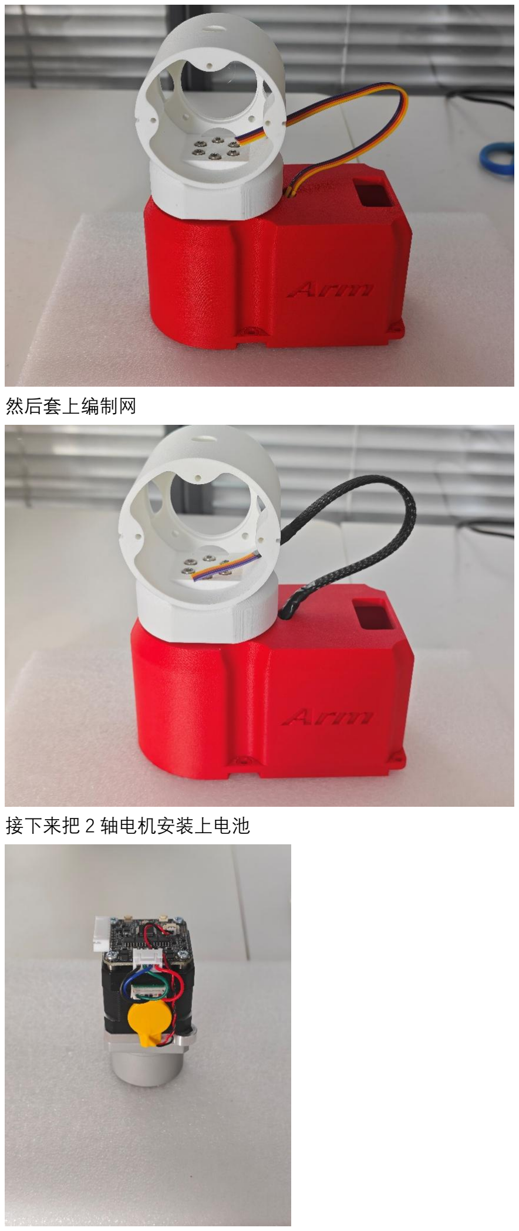
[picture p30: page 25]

然后套上编制网

接下来把 2 轴电机安装上电池

把带电池的一面朝下安装到关节 2 里面

找到带有圆弧边的对角位置，用两颗 M4*18mm 螺丝固定住

然后再用两颗 M4*10mm 的螺丝固定

用刚才的对半剪的通讯线安装到驱动板上，并且从关节 2 上面的圆孔插入一根通讯线

把通讯线往里塞一下，然后把多余的线剪去

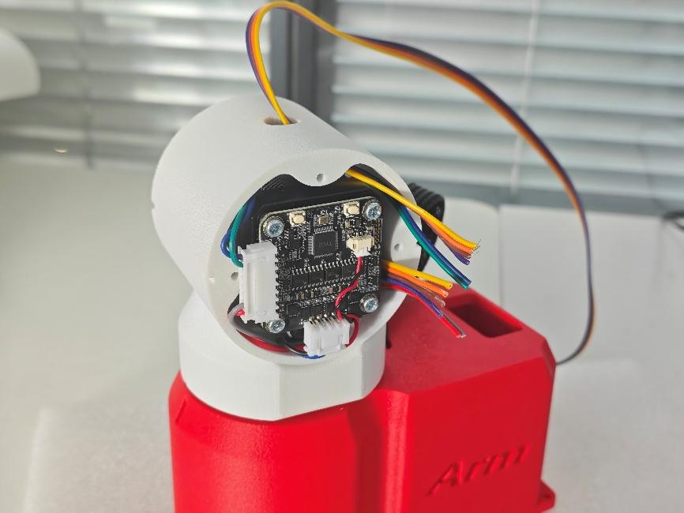
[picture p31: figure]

根据下图把线焊接起来
（正极）红对黄
（负极）灰对橙
（H）绿对棕
（L）蓝对紫

把所有线塞进去

然后把驱动板上 8P 的端口取下来

翘两边慢慢的就可以取出来

接着那 3 根 M3*30mm 的螺丝

里面有三个孔，用螺丝打进去，需要注意不要压到线

打到螺丝刚好露出来

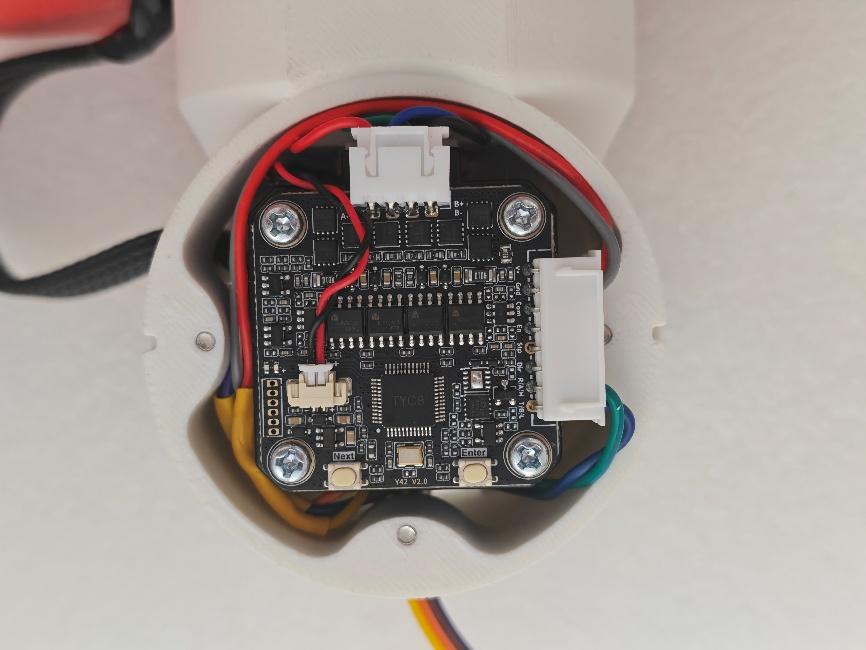
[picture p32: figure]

然后连接电脑，用上位机连接测试一下这两轴能不能动，有没有问题，需要注意通讯线的正 负极不要碰到一起，不然会烧驱动板

连接到上位机后点击关节微调进行测试一下，没有问题就可以继续安装了

接下来找到关节 2 同步后盖跟关节 3 同步后盖
要区分好，不要搞错了

给这两个后安装上 M3 螺母

并且在螺丝跟 3d 打印件缝隙上胶水，这样使其根牢靠不易掉落

然后再给正面也安装 M3 螺母根上胶水

把关节 2 同步后盖跟关节 3 同步后盖都按照上面流程完成后，拿出以下物件 关节 2 同步后盖
关节 2 同步后盖支撑
20*30*7 轴承

把轴承安装到关节 2 同步后盖支撑上

再把关节 2 同步后盖按到轴承上

找到 10*3*4 轴承根 M3*10mm 的螺丝

安装到关节 2 同步后盖支撑的正面，注意！不要拧太紧，需要有一点松动即可，不然轴承就 不起作用了

然后把这个组件安装到关节 2 上

把里面的 3 颗螺丝打紧

完成拿出刚才安装了轴承的关节 2 法兰支撑

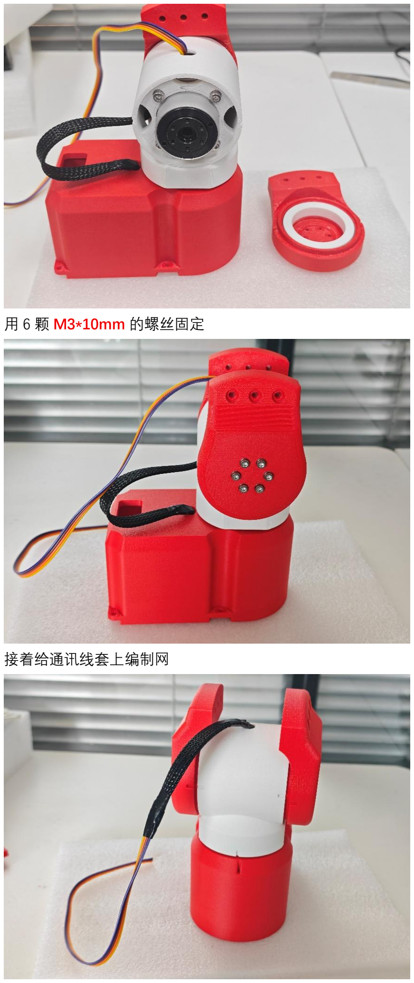
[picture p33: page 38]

用 6 颗 M3*10mm 的螺丝固定

接着给通讯线套上编制网

拿出以下物件

给大臂杆安装 M4 螺母

用 4 颗 M4*14mm 的螺丝把大臂杆根大臂连接 1 进行组装

给大臂连接 1 里面的螺母卡槽安装 6 颗 M4 螺母

然后用 6 颗 M4*22mm 的螺丝根关节 2 进行连接组装

用 4 颗 M4*14mm 的螺丝把大臂杆根关节 3 进行组装 并且把通讯线往大臂里面塞一下，不用露出来太多

接着给 3 轴电机安装电池

电机端口朝大臂方向安装

接着用 2 颗 M4*18mm 的螺丝固定法兰带有圆弧的两个螺丝孔

再用 2 颗 M4*12mm 的螺丝把剩下的孔位固定住

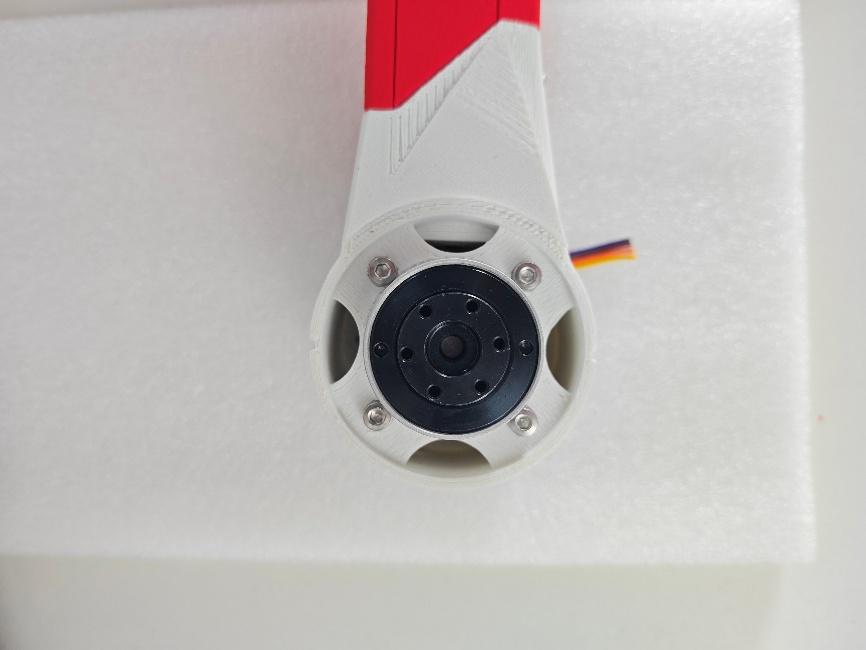
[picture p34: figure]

接着把驱动板的 8P 端口取下来

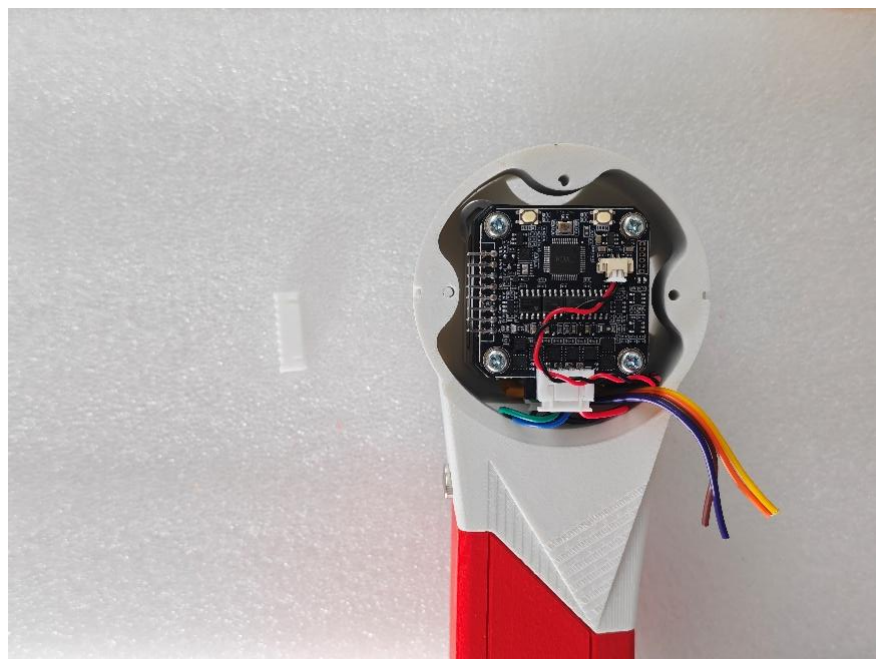
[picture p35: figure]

把通信线接上，长度大概如图
（正极）红对黄
（负极）灰对橙
（H）绿对棕
（L）蓝对紫

接着拿 3 根 M3*30mm 的螺丝先拧到孔里面

拧到刚好出来就可以了

把关节 3 法兰支撑根关节 3 同步后盖安装起来

把 10*3*4 轴承跟 M3*10mm 的螺丝安装到后面

接着安装到关节 3 上，并且拧紧里面的三颗螺丝

尽量把同步后盖贴近关节 3

拿出关节 3 法兰支撑跟轴承，安装起来

用 6 颗 M3*8mm 的螺丝把关节 3 法兰支撑跟关节 3 固定起来

接下安装第 4 轴的电池，并且把驱动板 8P 端口取下来

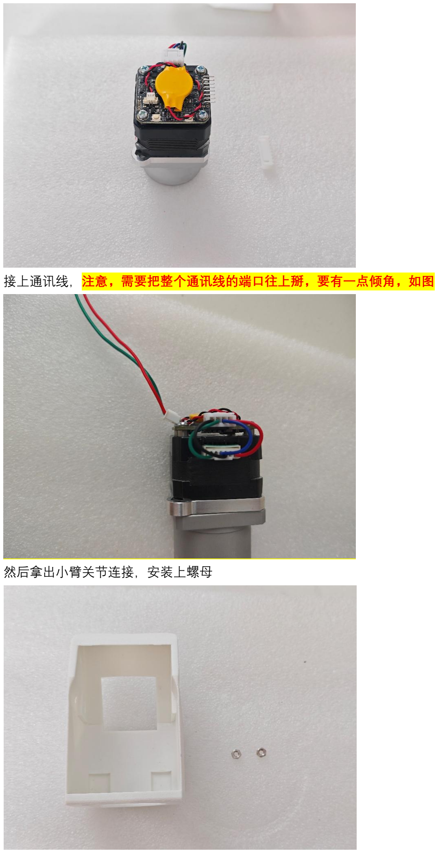
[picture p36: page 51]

接上通讯线，注意，需要把整个通讯线的端口往上掰，要有一点倾角，如图

然后拿出小臂关节连接，安装上螺母

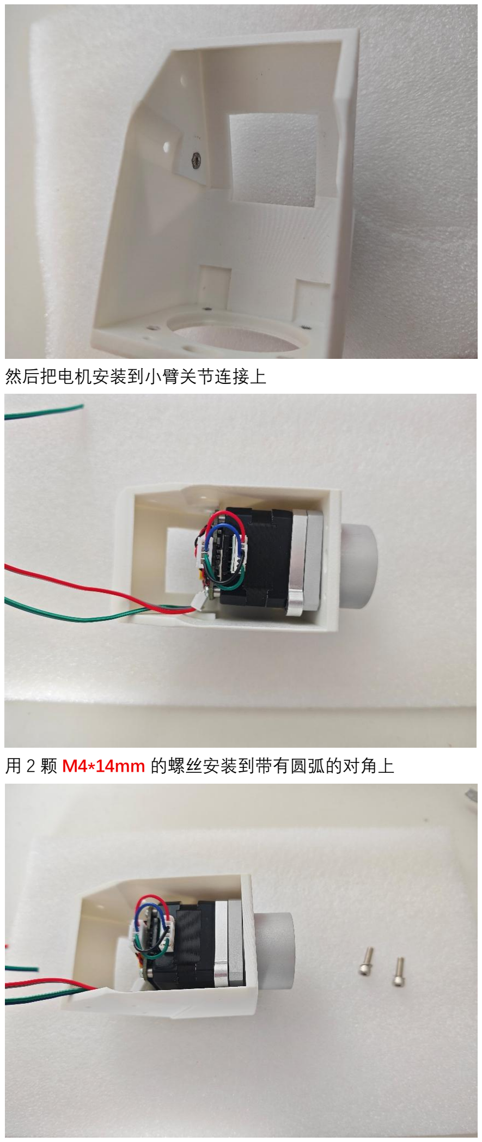
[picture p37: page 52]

然后把电机安装到小臂关节连接上

用 2 颗 M4*14mm 的螺丝安装到带有圆弧的对角上

再用 2 颗 M4*10mm 的螺丝把剩下的螺丝装上

接着给通讯线套上编制网

然后用两颗 M3*12mm 的螺丝把小臂连接进行固定一下

固定这个位置，以及这个孔的对面

再找一根通讯线从小臂连接上的孔穿进来

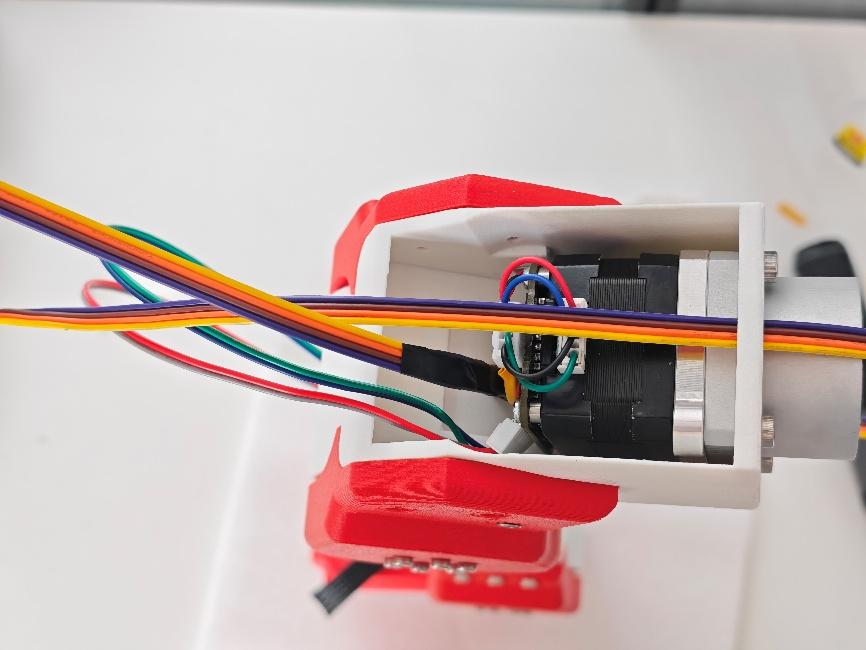
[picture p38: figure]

修剪长度根图片上差不多就可以了

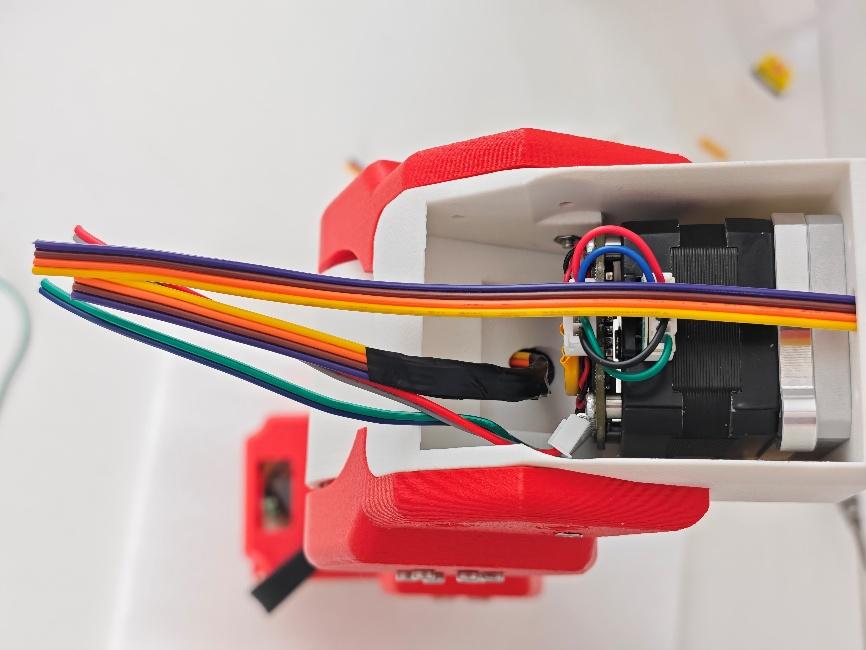
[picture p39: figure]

把这些线焊接起来
（正极）红对黄
（负极）灰对橙
（H）绿对棕
（L）蓝对紫

拿出小臂关节盖板根 4 颗 M3 螺母

安装上螺母

然后安装到小臂关节连接上

用 2 颗 M3*8mm 的螺丝固定小臂关节盖板根小臂关节连接

接着用 4 颗 M3*15mm 的螺丝把小臂关节连接固定起来

固定这个两个孔以及对面的两个

拿出小臂长根 6 颗 M3*12mm 的螺丝把小臂长固定在 4 轴法兰上

给通讯线修剪长度大概 23cm 左右

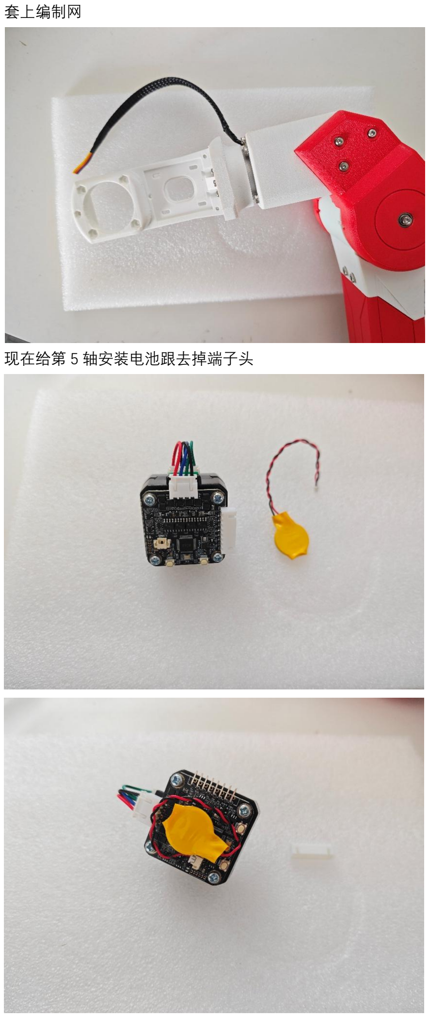
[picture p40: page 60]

套上编制网

现在给第 5 轴安装电池跟去掉端子头

用 4 颗 M3*8mm 螺丝稍微固定一下电机，不用太紧，待会还要拆下来的

拿出谐波 11-30 减速器、D 型杆、42 斜坡后盖

先把 D 型杆安装到波发生器上，然后这里的大概长度留 12mm 就可以了

给减速器抹上润滑脂后安装上波发生器

然后装上 42 谐波后盖

把谐波减速器安装到小臂长上，然后拿 4 颗 M4*20、4 颗 M4 螺母、2 颗 M3 螺母

安装上螺母

固定减速器并且按照剩下的 M3 螺母

拿出 20gt 同步轮、GPA-20GT、同步带

装上同步轮，看一下是否平行

当位置可以后，取小电机，把同步轮的螺丝拧紧

把电机装回去，但是先不要拧螺丝，先套上同步带，然后看看松紧度，当可以的时候再把电 机固定到小臂长上

接着找了通讯线，带有插头的

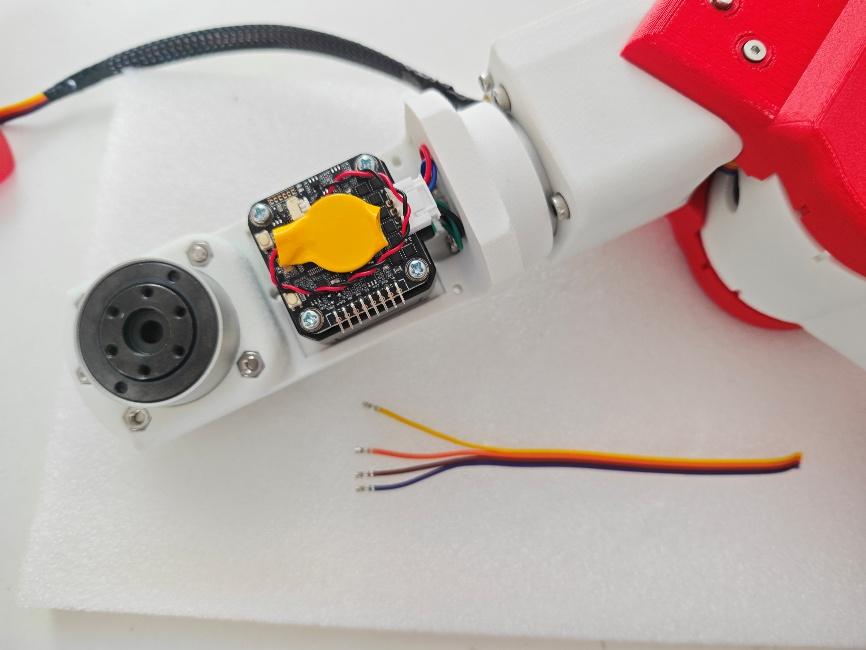
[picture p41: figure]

跟这个线序插到驱动板上
黄对正极
橙对负极
灰对 H
蓝对 L

然后把针脚跟通讯线焊接起来，并且套上热缩管

把通讯线从电机端口下面穿到上面来

长度修剪如图所示，注意：线一定不能太长，因为 5 轴空间有限

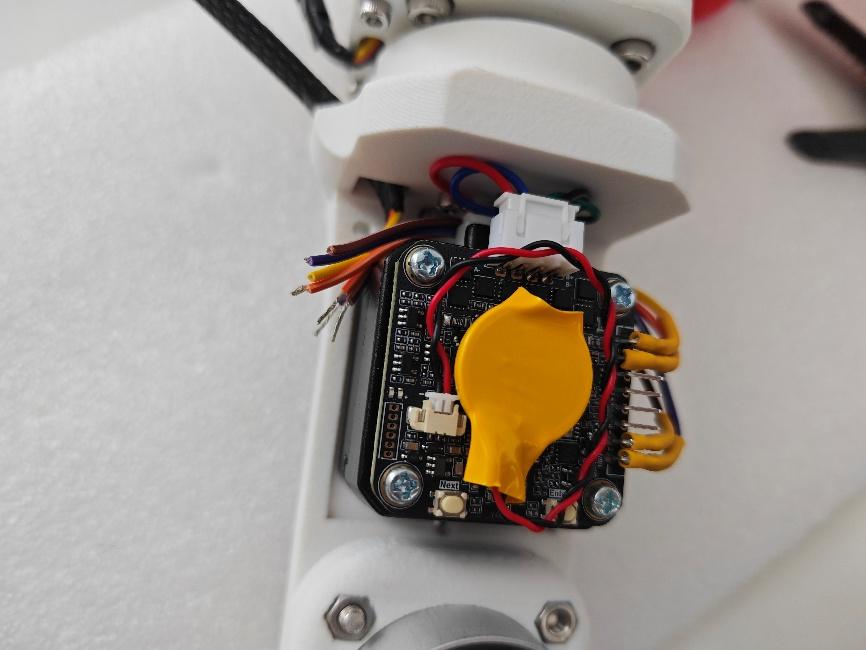
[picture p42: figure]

然后再拿一根通讯线进行焊接

这里焊接会比较难，建议是把电机拆下来，焊接完后再装回去 这里的线序就焊接相同颜色即可

焊接完成后安装回电机根同步带

把通讯线穿过小臂侧盖 2

拿一根 M3*45mm 的螺丝，安装上小臂侧盖 2

然后拿出小臂测盖 1 安装到小臂长侧边

用 2 根 M3*50 根 1 根 M3*30 的螺丝固定小臂侧盖 1

拿出 6 关节模块根 6 颗 M3*8mm 的螺丝

固定起来，并且修剪通讯线，大概 20cm 即可

套上编制网

给 6 轴电机安装电池根去掉端口，同时安装上通讯线

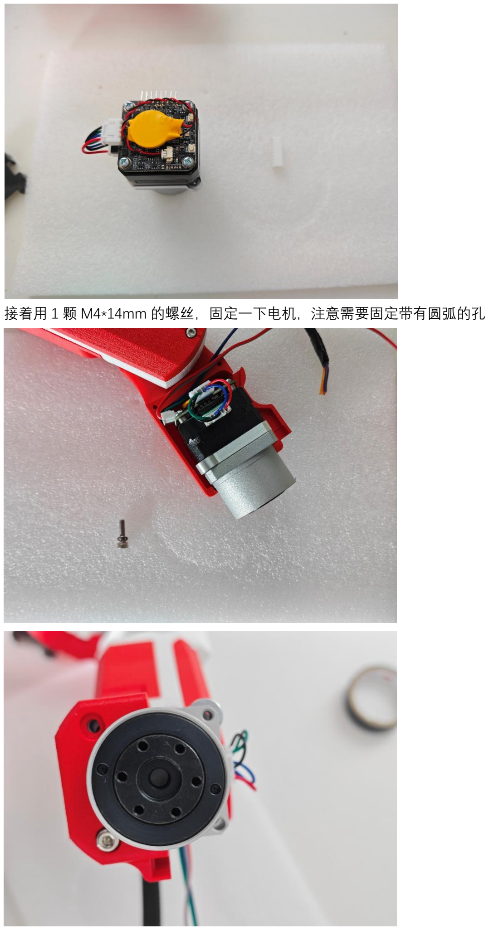
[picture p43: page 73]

接着用 1 颗 M4*14mm 的螺丝，固定一下电机，注意需要固定带有圆弧的孔

接着修剪通讯线，长度大概这么长，注意:第 6 轴内部空间有限，线不能太长

拿来 XH2.54 对插端子线

把 XH2.54 对插端子线、电机通讯线，以及上一轴的通讯线焊接起来 这里焊接比较难，需要把电机取下来焊接，焊接完成再装回去 焊接成这样， 以下面表格颜色顺序
| XH2.54 对插端子线 | 电机通讯线 | 上一轴的通讯线
正极 | 黄 | 红 | 黄
负极 | 白 | 灰 | 橙
H | 红 | 绿 | 棕
L | 黑 | 蓝 | 紫

焊接完后安装回电机根卡好 XH2.54 对插端子线

然后往这里上点胶水固定牢靠点

把剩下的 6 关节模块盖板安装上去

用两根 M3*45mm 的螺丝固定起来

最后，把底座的调试电源根 OmniCAN 取出来

准备好 Hub、转接线、电源开关、OmniCAN

把 Hub 根转接线如图所示安装

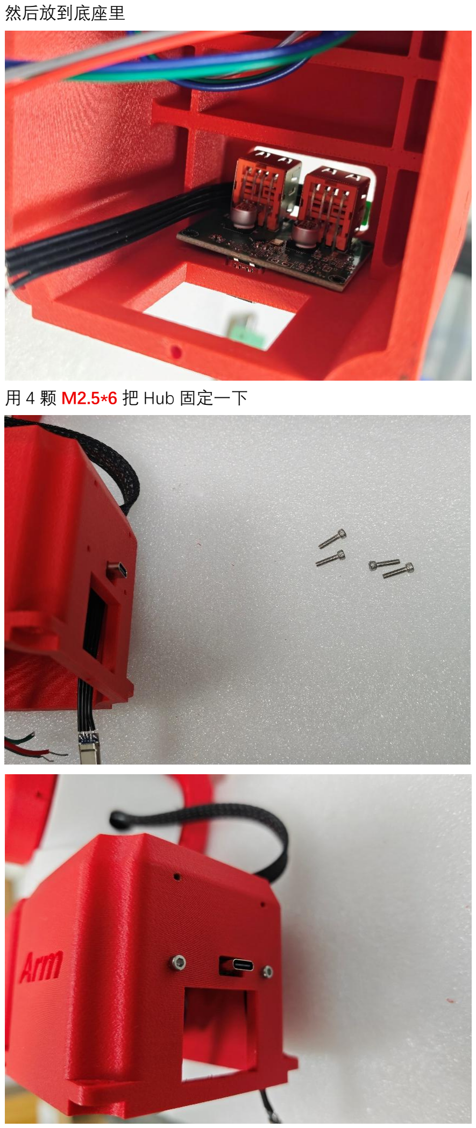
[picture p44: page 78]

然后放到底座里

用 4 颗 M2.5*6 把 Hub 固定一下

然后这个电源开关要按下图进行安装，不然后续焊线就有问题

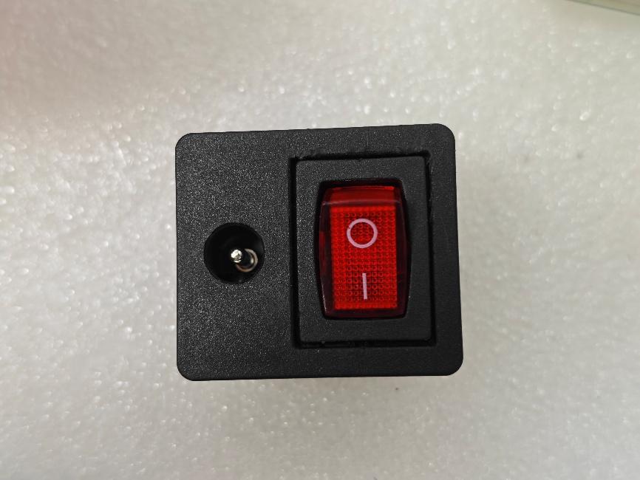
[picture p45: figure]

首先焊接这两根线

然后把正负极接上

接着就安装到底座后面

最后把 OmniCAN 安装连接起来

装上底座改变就完成了机械臂的组装

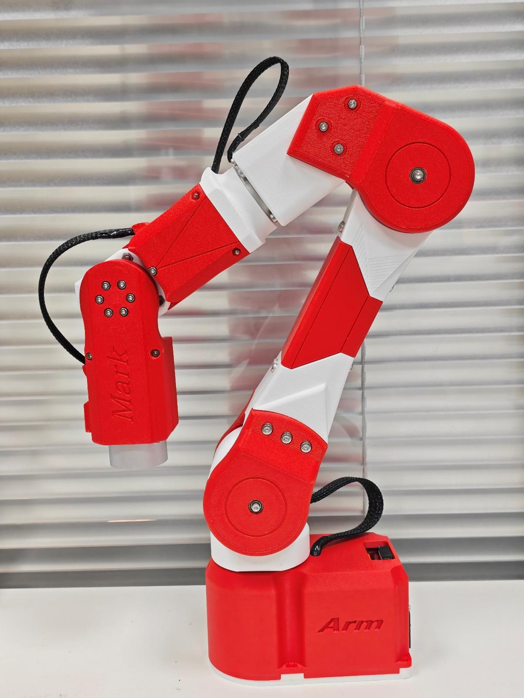
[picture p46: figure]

# 组装机械臂与夹爪

首先把夹爪拆成这样

再把后盖拆出来

把后盖装到机械臂末端的法兰上。用 6 颗 M3*8mm 的螺丝固定

然后把电机装上

最好把夹爪的末端部分装上

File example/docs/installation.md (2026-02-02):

# 安装与环境

本项目面向 **Python 脚本/二次开发** 的推荐入口是 `Embodied_SDK`；底层电机控制使用 `Horizon_Core/Control_SDK` 的 **UCP 硬件保护模式**（OmniCAN 串口 115200）。

---

## 1. 系统要求

- **Python**：3.12+（推荐与 `requirements.txt` 保持一致）
- **操作系统**：Windows 10/11（也可在 Ubuntu 20.04+ 以纯脚本方式运行）
- **硬件（真实机械臂）**：
  - ZDT 闭环驱动板 + CAN 总线
  - OmniCAN（UCP 模式，电脑侧表现为普通串口）

---

## 2. 安装依赖（推荐）

在项目根目录执行：

```bash
pip install -r requirements.txt
```

### 2.1 常见依赖说明

- **电机控制**：`pyserial`
- **视觉/跟踪（可选）**：`opencv-contrib-python`
- **GUI（可选）**：`PyQt5`
- **AI（可选）**：`dashscope`、`openai`、`PyYAML`、`python-dotenv` 等

### 2.2 Windows 安装 pyaudio（可选）

部分环境下 `pyaudio` 需要额外步骤（仅在使用麦克风 ASR/TTS 播放等功能时需要）：

```bash
pip install pipwin && pipwin install pyaudio
```

---

## 3. 可选组件

### 3.1 MuJoCo 数字孪生（可选）

如果要运行 `DigitalTwinSDK` 或 `example/mujoco_control.py`：

```bash
pip install mujoco
```

### 3.2 Joy-Con 手柄（可选）

如果要运行 `JoyconSDK` 或 `example/control_sdk_examples/joycon_control_example.py`：

- 依赖：`joycon-python`、`hidapi`（已在 `requirements.txt` 中列出）
- 手柄需要在系统蓝牙中完成配对

---

## 4. 验证安装

建议按以下顺序验证（从“最小依赖”到“完整系统”）：

1. **单电机入门**：`example/quickstart_guide.py`
2. **完整交互示例**：`example/sdk_quickstart.py`
3. **多机同步（Y42）**：`example/control_sdk_examples/multi_motor_sync_example.py`
4. **视觉/仿真/手柄/AI**：按需运行对应示例

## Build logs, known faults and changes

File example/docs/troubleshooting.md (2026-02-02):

# 常见问题与故障排查

## 连接与通信

### 无法连接电机（串口打开失败）

检查项：
- 串口号是否正确（Windows 设备管理器）
- 是否被其他程序占用
- USB 转 CAN 设备驱动是否正常

### 电机无响应

检查项：
- 驱动板 CAN 速率是否与程序一致
- 电机 ID 是否正确且不冲突
- 是否已经使能

## 运动控制

### 运动到位判断不稳定

建议：
- 避免多个程序同时读写同一条总线
- 在高频控制场景中，将读状态与写命令做串行化

## 视觉与相机

### 摄像头打不开

检查项：
- `camera_id` 是否正确
- 摄像头是否被其他程序占用
- OpenCV 是否安装完整

### 抓取位置明显偏差

检查项：
- 是否使用了匹配当前相机/安装位姿的标定文件
- 是否正确设置 TCP 偏移与抓取深度参数

## 仿真

### 仿真无法启动

检查项：
- 是否安装 `mujoco`（仅在你需要仿真时才需要）：`pip install mujoco`
- 显卡与 OpenGL 环境是否可用
- 模型文件是否存在：`config/urdf/mjmodel.xml`

参考：
- `example/mujoco_control.py`
- `example/docs/simulation.md`

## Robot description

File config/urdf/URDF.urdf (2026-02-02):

<?xml version="1.0" encoding="utf-8"?>
<!-- This URDF was automatically created by SolidWorks to URDF Exporter! Originally created by Stephen Brawner (brawner@gmail.com) 
     Commit Version: 1.6.0-4-g7f85cfe  Build Version: 1.6.7995.38578
     For more information, please see http://wiki.ros.org/sw_urdf_exporter -->
<robot name="URDF">
  <link name="base_link">
    <inertial>
      <origin xyz="-0.02836 -4.4462E-05 0.044361" rpy="0 0 0" />
      <mass value="0.26772" />
      <inertia ixx="0.00027289" ixy="-2.2748E-07" ixz="9.3612E-06" iyy="0.0005214" iyz="-1.2566E-07" izz="0.00060502" />
    </inertial>
    <visual>
      <origin xyz="0 0 0" rpy="0 0 0" />
      <geometry>
        <mesh filename="package://URDF/meshes/base_link.STL" />
      </geometry>
      <material name="">
        <color rgba="0.3 0.3 0.3 1" />
      </material>
    </visual>
    <collision>
      <origin xyz="0 0 0" rpy="0 0 0" />
      <geometry>
        <mesh filename="package://URDF/meshes/base_link.STL" />
      </geometry>
    </collision>
  </link>
  <link name="Link_1">
    <inertial>
      <origin xyz="-7.774E-05 0.0024015 0.024841" rpy="0 0 0" />
      <mass value="0.15256" />
      <inertia ixx="7.5659E-05" ixy="-7.4947E-09" ixz="-1.2782E-07" iyy="9.962E-05" iyz="1.2759E-06" izz="9.5018E-05" />
    </inertial>
    <visual>
      <origin xyz="0 0 0" rpy="0 0 0" />
      <geometry>
        <mesh filename="package://URDF/meshes/Link_1.STL" />
      </geometry>
      <material name="">
        <color rgba="0.60 0.60 0.60 1" />
      </material>
    </visual>
    <collision>
      <origin xyz="0 0 0" rpy="0 0 0" />
      <geometry>
        <mesh filename="package://URDF/meshes/Link_1.STL" />
      </geometry>
    </collision>
  </link>
  <joint name="Join_1" type="revolute">
    <origin xyz="0 0 0.0935" rpy="0 0 -3.1416" />
    <parent link="base_link" />
    <child link="Link_1" />
    <axis xyz="0 0 1" />
    <limit lower="-1.57" upper="1.57" effort="0" velocity="0" />
  </joint>
  <link name="Link_2">
    <inertial>
      <origin xyz="0.11951 0.00083958 -0.0022729" rpy="0 0 0" />
      <mass value="0.5162" />
      <inertia ixx="0.00024182" ixy="4.8736E-07" ixz="-1.272E-06" iyy="0.00034108" iyz="9.04E-09" izz="0.0003811" />
    </inertial>
    <visual>
      <origin xyz="0 0 0" rpy="0 0 0" />
      <geometry>
        <mesh filename="package://URDF/meshes/Link_2.STL" />
      </geometry>
      <material name="">
        <color rgba=" 0.3 0.3 0.3 1" />
      </material>
    </visual>
    <collision>
      <origin xyz="0 0 0" rpy="0 0 0" />
      <geometry>
        <mesh filename="package://URDF/meshes/Link_2.STL" />
      </geometry>
    </collision>
  </link>
  <joint name="Join_2" type="revolute">
    <origin xyz="0 0 0.037" rpy="1.5708 -1.5708 0" />
    <parent link="Link_1" />
    <child link="Link_2" />
    <axis xyz="0 0 -1" />
    <limit lower="-1.57" upper="1.57" effort="0" velocity="0" />
  </joint>
  <link name="Link_3">
    <inertial>
      <origin xyz="0.034957 0.030978 -0.0025668" rpy="0 0 0" />
      <mass value="0.21445" />
      <inertia ixx="0.00014358" ixy="-2.0639E-05" ixz="4.0365E-07" iyy="0.00015064" iyz="1.4899E-07" izz="0.00021689" />
    </inertial>
    <visual>
      <origin xyz="0 0 0" rpy="0 0 0" />
      <geometry>
        <mesh filename="package://URDF/meshes/Link_3.STL" />
      </geometry>
      <material name="">
        <color rgba="0.60 0.60 0.60 1" />
      </material>
    </visual>
    <collision>
      <origin xyz="0 0 0" rpy="0 0 0" />
      <geometry>
        <mesh filename="package://URDF/meshes/Link_3.STL" />
      </geometry>
    </collision>
  </link>
  <joint name="Join_3" type="revolute">
    <origin xyz="0.23441 -0.00016737 0" rpy="0 0 0" />
    <parent link="Link_2" />
    <child link="Link_3" />
    <axis xyz="0 0 -1" />
    <limit lower="-1.57" upper="1.57" effort="0" velocity="0" />
  </joint>
  <link name="Link_4">
    <inertial>
      <origin xyz="9.7548E-05 0.0027098 0.052183" rpy="0 0 0" />
      <mass value="0.16944" />
      <inertia ixx="0.00024964" ixy="-8.4822E-08" ixz="-5.687E-08" iyy="0.0002759" iyz="-5.2652E-06" izz="6.3269E-05" />
    </inertial>
    <visual>
      <origin xyz="0 0 0" rpy="0 0 0" />
      <geometry>
        <mesh filename="package://URDF/meshes/Link_4.STL" />
      </geometry>
      <material name="">
        <color rgba="0.3 0.3 0.3 1" />
      </material>
    </visual>
    <collision>
      <origin xyz="0 0 0" rpy="0 0 0" />
      <geometry>
        <mesh filename="package://URDF/meshes/Link_4.STL" />
      </geometry>
    </collision>
  </link>
  <joint name="Join_4" type="revolute">
    <origin xyz="0.047976 0.10644 0" rpy="-1.5708 0 0" />
    <parent link="Link_3" />
    <child link="Link_4" />
    <axis xyz="0 0 1" />
    <limit lower="-1.57" upper="1.57" effort="0" velocity="0" />
  </joint>
  <link name="Link_5">
    <inertial>
      <origin xyz="0.00071725 0.057508 0.0063657" rpy="0 0 0" />
      <mass value="0.11931" />
      <inertia ixx="8.4128E-05" ixy="-2.5128E-06" ixz="1.2888E-07" iyy="3.8236E-05" iyz="3.8017E-06" izz="0.00010251" />
    </inertial>
    <visual>
      <origin xyz="0 0 0" rpy="0 0 0" />
      <geometry>
        <mesh filename="package://URDF/meshes/Link_5.STL" />
      </geometry>
      <material name="">
        <color rgba="0.60 0.60 0.60 1" />
      </material>
    </visual>
    <collision>
      <origin xyz="0 0 0" rpy="0 0 0" />
      <geometry>
        <mesh filename="package://URDF/meshes/Link_5.STL" />
      </geometry>
    </collision>
  </link>
  <joint name="Join_5" type="revolute">
    <origin xyz="0 0 0.094" rpy="1.5708 0 0" />
    <parent link="Link_4" />
    <child link="Link_5" />
    <axis xyz="0 0 1" />
    <limit lower="-1.57" upper="1.57" effort="0" velocity="0" />
  </joint>
  <link name="Link_6">
    <inertial>
      <origin xyz="0.0072949 2.9723E-05 0.043104" rpy="0 0 0" />
      <mass value="0.15876" />
      <inertia ixx="5.3653E-05" ixy="-6.6623E-07" ixz="6.9126E-07" iyy="3.237E-05" iyz="6.2735E-08" izz="6.6122E-05" />
    </inertial>
    <visual>
      <origin xyz="0 0 0" rpy="0 0 0" />
      <geometry>
        <mesh filename="package://URDF/meshes/Link_6.STL" />
      </geometry>
      <material name="">
        <color rgba="0.3 0.3 0.3 1" />
      </material>
    </visual>
    <collision>
      <origin xyz="0 0 0" rpy="0 0 0" />
      <geometry>
        <mesh filename="package://URDF/meshes/Link_6.STL" />
      </geometry>
    </collision>
  </link>
  <joint name="Join_6" type="revolute">
    <origin xyz="0 0.1194 0" rpy="-1.5708 0 0" />
    <parent link="Link_5" />
    <child link="Link_6" />
    <axis xyz="0 0 1" />
    <limit lower="-1.57" upper="1.57" effort="0" velocity="0" />
  </joint>
</robot>

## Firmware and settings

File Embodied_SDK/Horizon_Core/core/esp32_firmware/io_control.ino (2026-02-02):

/*
 * ESP32 IO控制固件
 * 用于与上位机进行串口通信，控制数字输入输出
 * 
 * 硬件连接：
 * DI0-DI7: GPIO 23, 22, 17, 16, 21, 19, 18, 5 (前5个启用内部上拉)
 * DO0-DO7: GPIO 2, 4, 25, 26, 27, 32, 33, 13
 * 
 * 通信协议：115200 8N1
 */

 #include <Arduino.h>
 #include <ArduinoJson.h>
 
 // 版本信息
 #define FIRMWARE_VERSION "v1.0.0"
 
// IO引脚定义
const int DI_PINS[8] = {23, 22, 17, 16, 21, 19, 18, 5};  // 数字输入引脚
const int DO_PINS[8] = {2, 4, 25, 26, 27, 32, 33, 13};   // 数字输出引脚（使用可靠的数字IO引脚）
 
 // IO状态
 bool di_states[8] = {false};
 bool do_states[8] = {false};
 // 针对特定GPIO配置上拉电阻：GPIO23、22、17、16、21启用上拉，其他禁用
bool di_pullup_enabled[8] = {true, true, true, true, true, false, false, false};  // DI0-DI4(GPIO23,22,17,16,21)=true, 其他=false
 
 // 中断相关
 volatile bool di_interrupt_flags[8] = {false};
 int di_interrupt_modes[8] = {0};  // 0:NONE, 1:RISING, 2:FALLING, 3:BOTH
 
// DI中断相关（基于固定引脚）
volatile bool di_interrupt_flags_ext[8] = {false};  // 扩展DI中断标志
int di_interrupt_modes_ext[8] = {0};  // 0:NONE, 1:RISING, 2:FALLING, 3:BOTH, 4:LOW_LEVEL
 
// 脉冲输出相关（保留传统DO脉冲功能）
unsigned long pulse_start_time[8] = {0};
unsigned long pulse_duration[8] = {0};
bool pulse_active[8] = {false};
 
 // 串口缓冲区
 String command_buffer = "";
 bool command_ready = false;
 
 // 函数声明
 void setup_io_pins();
 void handle_command(String command);
 void send_response(String response);
 void update_di_states();
 void update_pulse_outputs();
 void setup_interrupts();
 void IRAM_ATTR di_interrupt_handler_0();
 void IRAM_ATTR di_interrupt_handler_1();
 void IRAM_ATTR di_interrupt_handler_2();
 void IRAM_ATTR di_interrupt_handler_3();
 void IRAM_ATTR di_interrupt_handler_4();
 void IRAM_ATTR di_interrupt_handler_5();
 void IRAM_ATTR di_interrupt_handler_6();
 void IRAM_ATTR di_interrupt_handler_7();
 
 void setup() {
   // 初始化串口
   Serial.begin(115200);
   delay(100);  // 等待串口稳定，移除可能导致卡死的while循环
   
   // 初始化IO引脚
   setup_io_pins();
   
   // 设置中断
   setup_interrupts();
   
   // 发送启动信息
   Serial.println("ESP32 IO Controller Ready");
   Serial.println("Firmware Version: " + String(FIRMWARE_VERSION));
 }
 
void loop() {
  // 处理串口命令接收
  while (Serial.available()) {
    char c = Serial.read();
    // 检查是否为命令结束符（换行符）
    if (c == '\n') {
      command_ready = true;  // 标记命令接收完成
    } else if (c != '\r') {  // 忽略回车符，只处理其他字符
      command_buffer += c;   // 将字符添加到命令缓冲区
    }
  }
  
  // 如果命令接收完成，处理命令
  if (command_ready) {
    handle_command(command_buffer);  // 处理接收到的命令
    command_buffer = "";             // 清空命令缓冲区
    command_ready = false;           // 重置命令接收标志
  }
  
  // 更新IO状态和处理各种定时任务
  update_di_states();      // 更新所有DI引脚状态
  update_pulse_outputs();  // 处理DO脉冲输出定时
  update_di_interrupts();  // 检查DI扩展中断条件
  
  delay(1);  // 短暂延时，避免CPU占用过高
}
 
 
void setup_io_pins() {
  // 配置数字输入引脚
  for (int i = 0; i < 8; i++) {
    // 根据上拉电阻配置设置DI引脚模式
    if (di_pullup_enabled[i]) {
      pinMode(DI_PINS[i], INPUT_PULLUP);  // 启用内部上拉电阻
    } else {
      pinMode(DI_PINS[i], INPUT);         // 不使用内部上拉电阻
    }
  }
  
  // 配置数字输出引脚
  for (int i = 0; i < 8; i++) {
    pinMode(DO_PINS[i], OUTPUT);    // 设置为输出模式
    digitalWrite(DO_PINS[i], LOW);  // 初始化为低电平
    do_states[i] = false;           // 更新状态记录
  }
}
 
 void setup_interrupts() {
   // 中断处理函数数组
   void (*interrupt_handlers[8])() = {
     di_interrupt_handler_0, di_interrupt_handler_1,
     di_interrupt_handler_2, di_interrupt_handler_3,
     di_interrupt_handler_4, di_interrupt_handler_5,
     di_interrupt_handler_6, di_interrupt_handler_7
   };
   
   // 为每个DI引脚设置中断（默认不启用）
   for (int i = 0; i < 8; i++) {
     di_interrupt_modes[i] = 0;  // NONE
   }
 }
 
void handle_command(String command) {
  command.trim();
  
  // 【连接测试命令】处理PING命令，用于测试ESP32是否正常响应
  if (command == "PING") {
    send_response("PONG");
  }
  // 【版本查询命令】返回固件版本信息
  else if (command == "VERSION") {
    send_response("VER:" + String(FIRMWARE_VERSION));
  }
  // 【状态查询命令】返回ESP32运行状态信息（运行时间、内存、芯片型号）
  else if (command == "STATUS") {
    DynamicJsonDocument doc(200);
    doc["uptime"] = millis();
    doc["free_heap"] = ESP.getFreeHeap();
    doc["chip_id"] = ESP.getChipModel();
    
    String status_json;
    serializeJson(doc, status_json);
    send_response("STATUS:" + status_json);
  }
  // 【读取所有DI状态命令】返回DI0-DI7的状态，格式：DI:01010000
  else if (command == "READ_DI") {
    String di_data = "";
    for (int i = 0; i < 8; i++) {
      di_data += di_states[i] ? "1" : "0";
    }
    send_response("DI:" + di_data);
  }
  // 【读取单个DI状态命令】格式：READ_DI:3，返回指定DI引脚的状态
  else if (command.startsWith("READ_DI:")) {
    int pin = command.substring(8).toInt();
    // 检查DI引脚号是否有效（0-7）
    if (pin >= 0 && pin < 8) {
      send_response("DI" + String(pin) + ":" + (di_states[pin] ? "1" : "0"));
    } else {
      // DI引脚号无效，返回错误信息
      send_response("ERROR:Invalid DI pin");
    }
  }
  // 【设置单个DO状态命令】格式：SET_DO:3,1，设置指定DO引脚的状态
  else if (command.startsWith("SET_DO:")) {
    int comma_pos = command.indexOf(',');
    // 检查命令格式是否正确（必须包含逗号分隔符）
    if (comma_pos > 0) {
      int pin = command.substring(7, comma_pos).toInt();
      int state = command.substring(comma_pos + 1).toInt();
      
      // 检查DO引脚号是否有效（0-7）
      if (pin >= 0 && pin < 8) {
        digitalWrite(DO_PINS[pin], state ? HIGH : LOW);
        do_states[pin] = state;
        send_response("OK");
      } else {
        // DO引脚号无效，返回错误信息
        send_response("ERROR:Invalid DO pin");
      }
    } else {
      // 命令格式错误（缺少逗号或格式不正确）
      send_response("ERROR:Invalid SET_DO format");
    }
  }
  // 【设置所有DO状态命令】格式：SET_DO_ALL:01010000，一次性设置所有DO引脚状态
  else if (command.startsWith("SET_DO_ALL:")) {
    String states_str = command.substring(11);
    // 检查状态字符串长度是否为8（对应8个DO引脚）
    if (states_str.length() == 8) {
      for (int i = 0; i < 8; i++) {
        bool state = states_str.charAt(i) == '1';
        digitalWrite(DO_PINS[i], state ? HIGH : LOW);
        do_states[i] = state;
      }
      send_response("OK");
    } else {
      // 状态字符串长度不正确（不是8位）
      send_response("ERROR:Invalid DO states format");
    }
  }
  // 【读取所有DO状态命令】返回DO0-DO7的状态，格式：DO:01010000
  else if (command == "READ_DO") {
    String do_data = "";
    for (int i = 0; i < 8; i++) {
      do_data += do_states[i] ? "1" : "0";
    }
    send_response("DO:" + do_data);
  }
  // 【DO脉冲输出命令】格式：PULSE_DO:3,100，让指定DO引脚输出指定时长的脉冲
  else if (command.startsWith("PULSE_DO:")) {
    int comma_pos = command.indexOf(',');
    // 检查命令格式是否正确（必须包含逗号分隔符）
    if (comma_pos > 0) {
      int pin = command.substring(9, comma_pos).toInt();
      int duration_ms = command.substring(comma_pos + 1).toInt();
      
      // 检查DO引脚号和脉冲时长是否有效
      if (pin >= 0 && pin < 8 && duration_ms > 0) {
        // 启动脉冲输出
        digitalWrite(DO_PINS[pin], HIGH);
        do_states[pin] = true;
        pulse_active[pin] = true;
        pulse_start_time[pin] = millis();
        pulse_duration[pin] = duration_ms;
        
        send_response("OK");
      } else {
        // DO引脚号无效或脉冲时长无效
        send_response("ERROR:Invalid PULSE_DO parameters");
      }
    } else {
      // 命令格式错误（缺少逗号或格式不正确）
      send_response("ERROR:Invalid PULSE_DO format");
    }
  }
  // 【复位所有DO命令】将所有DO引脚设置为低电平并停止所有脉冲输出
  else if (command == "RESET_DO") {
    for (int i = 0; i < 8; i++) {
      digitalWrite(DO_PINS[i], LOW);
      do_states[i] = false;
      pulse_active[i] = false;
    }
    send_response("OK");
  }
  // 【配置DI上拉电阻命令】格式：CONFIG_PULLUP:3,1，配置指定DI引脚的上拉电阻
  else if (command.startsWith("CONFIG_PULLUP:")) {
    int comma_pos = command.indexOf(',');
    // 检查命令格式是否正确（必须包含逗号分隔符）
    if (comma_pos > 0) {
      int pin = command.substring(14, comma_pos).toInt();
      int enable = command.substring(comma_pos + 1).toInt();
      
      // 检查DI引脚号是否有效（0-7）
      if (pin >= 0 && pin < 8) {
        di_pullup_enabled[pin] = enable;
        // 根据enable参数设置引脚模式
        if (enable) {
          pinMode(DI_PINS[pin], INPUT_PULLUP);  // 启用上拉电阻
        } else {
          pinMode(DI_PINS[pin], INPUT);         // 禁用上拉电阻
        }
        send_response("OK");
      } else {
        // DI引脚号无效，返回错误信息
        send_response("ERROR:Invalid DI pin");
      }
    } else {
      // 命令格式错误（缺少逗号或格式不正确）
      send_response("ERROR:Invalid CONFIG_PULLUP format");
    }
  }
  // 【配置DI硬件中断命令】格式：CONFIG_INT:3,RISING，配置指定DI引脚的硬件中断模式
  else if (command.startsWith("CONFIG_INT:")) {
    int comma_pos = command.indexOf(',');
    // 检查命令格式是否正确（必须包含逗号分隔符）
    if (comma_pos > 0) {
      int pin = command.substring(11, comma_pos).toInt();
      String mode = command.substring(comma_pos + 1);
      
      // 检查DI引脚号是否有效（0-7）
      if (pin >= 0 && pin < 8) {
        // 先分离现有中断
        detachInterrupt(digitalPinToInterrupt(DI_PINS[pin]));
        
        // 配置新的中断模式
        void (*interrupt_handlers[8])() = {
          di_interrupt_handler_0, di_interrupt_handler_1,
          di_interrupt_handler_2, di_interrupt_handler_3,
          di_interrupt_handler_4, di_interrupt_handler_5,
          di_interrupt_handler_6, di_interrupt_handler_7
        };
        
        // 根据中断模式字符串配置相应的硬件中断
        if (mode == "RISING") {
          di_interrupt_modes[pin] = 1;  // 上升沿中断
          attachInterrupt(digitalPinToInterrupt(DI_PINS[pin]), interrupt_handlers[pin], RISING);
        } else if (mode == "FALLING") {
          di_interrupt_modes[pin] = 2;  // 下降沿中断
          attachInterrupt(digitalPinToInterrupt(DI_PINS[pin]), interrupt_handlers[pin], FALLING);
        } else if (mode == "BOTH") {
          di_interrupt_modes[pin] = 3;  // 双边沿中断
          attachInterrupt(digitalPinToInterrupt(DI_PINS[pin]), interrupt_handlers[pin], CHANGE);
        } else if (mode == "NONE") {
          di_interrupt_modes[pin] = 0;  // 禁用中断
          // 中断已分离
        } else {
          // 中断模式无效，返回错误信息
          send_response("ERROR:Invalid interrupt mode");
          return;
        }
        
        send_response("OK");
      } else {
        // DI引脚号无效，返回错误信息
        send_response("ERROR:Invalid DI pin");
      }
    } else {
      // 命令格式错误（缺少逗号或格式不正确）
      send_response("ERROR:Invalid CONFIG_INT format");
    }
  }
  // 【读取DI硬件中断状态命令】返回触发了硬件中断的DI引脚列表
  else if (command == "READ_INT") {
    String int_pins = "";
    bool has_interrupt = false;
    
    // 遍历所有DI引脚，检查中断标志
    for (int i = 0; i < 8; i++) {
      if (di_interrupt_flags[i]) {
        // 如果已有中断引脚，添加逗号分隔符
        if (has_interrupt) {
          int_pins += ",";
        }
        int_pins += String(i);
        has_interrupt = true;
      }
    }
    
    // 根据是否有中断返回相应结果
    if (has_interrupt) {
      send_response("INT:" + int_pins);  // 返回触发中断的引脚列表
    } else {
      send_response("INT:NONE");         // 没有中断触发
    }
  }
  // 【清除DI硬件中断标志命令】格式：CLEAR_INT:3 或 CLEAR_INT:ALL
  else if (command.startsWith("CLEAR_INT:")) {
    String pin_str = command.substring(10);
    
    // 检查是否清除所有中断标志
    if (pin_str == "ALL") {
      for (int i = 0; i < 8; i++) {
        di_interrupt_flags[i] = false;
      }
      send_response("OK");
    } else {
      // 清除指定引脚的中断标志
      int pin = pin_str.toInt();
      // 检查DI引脚号是否有效（0-7）
      if (pin >= 0 && pin < 8) {
        di_interrupt_flags[pin] = false;
        send_response("OK");
      } else {
        // DI引脚号无效，返回错误信息
        send_response("ERROR:Invalid DI pin");
      }
    }
  }
  // 【配置DI扩展中断命令】格式：CONFIG_DI_INT:3,RISING，配置DI引脚的软件轮询中断模式
  else if (command.startsWith("CONFIG_DI_INT:")) {
    int comma_pos = command.indexOf(',');
    // 检查命令格式是否正确（必须包含逗号分隔符）
    if (comma_pos > 0) {
      int di_pin = command.substring(14, comma_pos).toInt();
      String mode = command.substring(comma_pos + 1);
      
      // 检查DI引脚号是否有效（0-7）
      if (di_pin >= 0 && di_pin < 8) {
        // 根据中断模式字符串设置扩展中断模式
        if (mode == "RISING") {
          di_interrupt_modes_ext[di_pin] = 1;      // 上升沿触发
        } else if (mode == "FALLING") {
          di_interrupt_modes_ext[di_pin] = 2;      // 下降沿触发
        } else if (mode == "BOTH") {
          di_interrupt_modes_ext[di_pin] = 3;      // 双边沿触发
        } else if (mode == "LOW_LEVEL") {
          di_interrupt_modes_ext[di_pin] = 4;      // 低电平触发
        } else if (mode == "NONE") {
          di_interrupt_modes_ext[di_pin] = 0;      // 禁用扩展中断
        } else {
          // 扩展中断模式无效，返回错误信息
          send_response("ERROR:Invalid DI interrupt mode");
          return;
        }
        send_response("OK");
      } else {
        // DI引脚号无效，返回错误信息
        send_response("ERROR:Invalid DI pin");
      }
    } else {
      // 命令格式错误（缺少逗号或格式不正确）
      send_response("ERROR:Invalid CONFIG_DI_INT format");
    }
  }
  // 【读取DI扩展中断状态命令】返回触发了扩展中断的DI引脚列表
  else if (command == "READ_DI_INT") {
    String int_pins = "";
    bool has_interrupt = false;
    
    // 遍历所有DI引脚，检查扩展中断标志
    for (int i = 0; i < 8; i++) {
      if (di_interrupt_flags_ext[i]) {
        // 如果已有中断引脚，添加逗号分隔符
        if (has_interrupt) {
          int_pins += ",";
        }
        int_pins += String(i);
        has_interrupt = true;
      }
    }
    
    // 根据是否有扩展中断返回相应结果
    if (has_interrupt) {
      send_response("DI_INT:" + int_pins);  // 返回触发扩展中断的引脚列表
    } else {
      send_response("DI_INT:NONE");         // 没有扩展中断触发
    }
  }
  // 【清除DI扩展中断标志命令】格式：CLEAR_DI_INT:3 或 CLEAR_DI_INT:ALL
  else if (command.startsWith("CLEAR_DI_INT:")) {
    String pin_str = command.substring(13);
    
    // 检查是否清除所有扩展中断标志
    if (pin_str == "ALL") {
      for (int i = 0; i < 8; i++) {
        di_interrupt_flags_ext[i] = false;
      }
      send_response("OK");
    } else {
      // 清除指定引脚的扩展中断标志
      int di_pin = pin_str.toInt();
      // 检查DI引脚号是否有效（0-7）
      if (di_pin >= 0 && di_pin < 8) {
        di_interrupt_flags_ext[di_pin] = false;
        send_response("OK");
      } else {
        // DI引脚号无效，返回错误信息
        send_response("ERROR:Invalid DI pin");
      }
    }
  }
  // 【未知命令处理】如果命令不匹配任何已知命令，返回UNKNOWN
  else {
    send_response("UNKNOWN");
  }
 }
 
 void send_response(String response) {
   Serial.println(response);
 }
 
 void update_di_states() {
   for (int i = 0; i < 8; i++) {
     di_states[i] = digitalRead(DI_PINS[i]) == HIGH;
   }
 }
 
void update_pulse_outputs() {
  unsigned long current_time = millis();
  
  // 检查所有DO引脚的脉冲输出状态
  for (int i = 0; i < 8; i++) {
    // 如果该引脚正在进行脉冲输出
    if (pulse_active[i]) {
      // 检查脉冲持续时间是否已到
      if (current_time - pulse_start_time[i] >= pulse_duration[i]) {
        // 脉冲时间到，结束脉冲输出
        digitalWrite(DO_PINS[i], LOW);  // 设置为低电平
        do_states[i] = false;           // 更新状态记录
        pulse_active[i] = false;        // 标记脉冲结束
      }
    }
  }
}

void update_di_interrupts() {
  // 轮询检查DI扩展中断条件（软件实现的中断检测）
  static bool previous_di_states[8] = {false};
  
  // 遍历所有DI引脚
  for (int i = 0; i < 8; i++) {
    // 如果该引脚配置了扩展中断模式
    if (di_interrupt_modes_ext[i] > 0) {
      bool current_state = di_states[i];
      bool previous_state = previous_di_states[i];
      
      // 检查中断触发条件
      bool trigger = false;
      switch (di_interrupt_modes_ext[i]) {
        case 1: // 上升沿触发：从低电平变为高电平
          trigger = current_state && !previous_state;
          break;
        case 2: // 下降沿触发：从高电平变为低电平
          trigger = !current_state && previous_state;
          break;
        case 3: // 双边沿触发：电平发生任何变化
          trigger = current_state != previous_state;
          break;
        case 4: // 低电平触发：当前为低电平
          trigger = !current_state;
          break;
      }
      
      // 如果满足触发条件，设置中断标志
      if (trigger) {
        di_interrupt_flags_ext[i] = true;
      }
      
      // 更新前一次状态记录
      previous_di_states[i] = current_state;
    }
  }
}
 
 
 // 中断处理函数
 void IRAM_ATTR di_interrupt_handler_0() { di_interrupt_flags[0] = true; }
 void IRAM_ATTR di_interrupt_handler_1() { di_interrupt_flags[1] = true; }
 void IRAM_ATTR di_interrupt_handler_2() { di_interrupt_flags[2] = true; }
 void IRAM_ATTR di_interrupt_handler_3() { di_interrupt_flags[3] = true; }
 void IRAM_ATTR di_interrupt_handler_4() { di_interrupt_flags[4] = true; }
 void IRAM_ATTR di_interrupt_handler_5() { di_interrupt_flags[5] = true; }
 void IRAM_ATTR di_interrupt_handler_6() { di_interrupt_flags[6] = true; }
 void IRAM_ATTR di_interrupt_handler_7() { di_interrupt_flags[7] = true; }
 

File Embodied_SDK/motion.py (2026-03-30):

#!/usr/bin/env python3
# -*- coding: utf-8 -*-
"""
运动控制 SDK 封装
================

目标：
- 在不改动现有底层实现的前提下，给关节运动 / 末端运动 / 预设动作提供一个
  无界面依赖、接口统一的高层封装，方便在 Web / ROS2 / 脚本中直接调用。

本模块只是对 `core.embodied_core.embodied_func` 中已有函数的**薄封装**：
- `c_a_j`  关节角度运动
- `e_p_a`  预设动作（从 preset_actions.json 读取）
"""

from __future__ import annotations

from typing import Dict, Any, List, Optional
import logging

from Horizon_Core import gateway as horizon_gateway
from Horizon_Core.core.arm_core.kinematics_factory import create_configured_kinematics

def _load_motor_config():
    """从 motor_config.json 加载电机配置（仅保留 Mark）。"""
    import os
    import json
    import sys
    
    # 默认配置
    config = {
        "motor_reducer_ratios": {
            # 默认减速比
            "1": 50.0, "2": 50.0, "3": 50.0, "4": 30.0, "5": 30.0, "6": 30.0
        },
        "motor_directions": {
            # 默认方向
            "1": -1, "2": 1, "3": 1, "4": -1, "5": -1, "6": 1
        }
    }
    
    try:
        # 源码运行：强制用项目内 ./config；打包运行：用外置可写配置目录
        if not getattr(sys, "frozen", False):
            current_dir = os.path.dirname(os.path.abspath(__file__))
            config_dir = os.path.join(os.path.dirname(current_dir), "config")
        else:
            config_dir = os.environ.get("HORIZONARM_CONFIG_DIR", "").strip()
            if not config_dir:
                data_root = os.environ.get("HORIZON_DATA_DIR", "").strip()
                if data_root:
                    cand = os.path.join(data_root, "config")
                    if os.path.isdir(cand):
                        config_dir = cand
            if not config_dir:
                current_dir = os.path.dirname(os.path.abspath(__file__))
                config_dir = os.path.join(os.path.dirname(current_dir), "config")

        def _safe_read(p: str) -> dict:
            try:
                if not os.path.exists(p):
                    return {}
                with open(p, "r", encoding="utf-8") as f:
                    return json.load(f) or {}
            except Exception:
                return {}

        config_path = os.path.join(config_dir, "motor_config.json")
        if config_path:
            loaded = _safe_read(config_path)
            if "motor_reducer_ratios" in loaded:
                config["motor_reducer_ratios"].update(loaded["motor_reducer_ratios"])
            if "motor_directions" in loaded:
                config["motor_directions"].update(loaded["motor_directions"])
    except Exception as e:
        print(f" ⚠️ [MotionSDK] 加载电机配置失败，使用默认值: {e}")
        
    return config

def create_motor_controller(*args, **kwargs) -> Any:
    """
    创建电机控制器实例（ZDTMotorController）。
    
    这是获取底层电机控制对象的推荐方式，内部会通过统一网关完成核心初始化与适配。
    """
    return horizon_gateway.create_motor_controller(*args, **kwargs)

def get_function_codes() -> Any:
    """
    获取底层功能码常量类 (FunctionCodes)。
    
    Returns:
        FunctionCodes 类，包含各类控制指令的功能码常量
    """
    Control_Core = horizon_gateway.get_control_core()
    return Control_Core.constants.FunctionCodes

def setup_logging(level=logging.INFO):
    """
    设置日志配置
    
    Args:
        level: 日志级别
    """
    logging.basicConfig(
        level=level,
        format='%(asctime)s - %(name)s - %(levelname)s - %(message)s',
        datefmt='%Y-%m-%d %H:%M:%S'
    )

def close_all_shared_interfaces():
    """关闭所有共享的 CAN 接口连接"""
    Control_Core = horizon_gateway.get_control_core()
    Control_Core.ZDTMotorController.close_all_shared_interfaces()

def get_shared_interface_info():
    """获取共享接口信息"""
    Control_Core = horizon_gateway.get_control_core()
    return Control_Core.ZDTMotorController.get_shared_interface_info()

class MotionSDK:
    """
    机械臂基础运动控制 SDK：
    - 与 GUI 解耦，仅依赖已有的 embodied_func / embodied_internal；
    - 主要面向：Web 后端、ROS2 节点、独立 Python 脚本等。
    """

    def __init__(self) -> None:
        # 缓存底层命令构建器类
        self._command_builder_cls = None

    # ------------------------------------------------------------------
    # 电机 & 运动参数绑定
    # ------------------------------------------------------------------

    def bind_motors(
        self,
        motors: Dict[int, Any],
        *,
        use_motor_config: bool = True,
        reducer_ratios: Optional[Dict[int, float]] = None,
        directions: Optional[Dict[int, int]] = None,
    ) -> None:
        """
        绑定真实机械臂电机实例。
        
        与 VisualGraspSDK 的 bind_motors 行为一致，最终都调用
        `embodied_internal._set_real_motors`。
        """
        if use_motor_config:
            config = _load_motor_config()
            all_ratios = {int(k): v for k, v in config["motor_reducer_ratios"].items()}
            all_dirs = {int(k): v for k, v in config["motor_directions"].items()}
            rr = {mid: all_ratios.get(mid, 16.0) for mid in motors.keys()}
            dd = {mid: all_dirs.get(mid, 1) for mid in motors.keys()}
        else:
            rr = reducer_ratios or {}
            dd = directions or {}

        embodied_internal = horizon_gateway.get_embodied_internal_module()
        embodied_internal._set_real_motors(motors, rr, dd)

    def unbind_motors(self) -> None:
        """
        解绑 / 清空真实机械臂电机绑定。

        本质上是调用 `embodied_internal._set_real_motors(None, None, None)`，
        用于在停止系统或断开机械臂时清理全局状态。
        """
        embodied_internal = horizon_gateway.get_embodied_internal_module()
        embodied_internal._set_real_motors(None, None, None)

    def set_motion_params(
        self,
        max_speed: int = 100,
        acceleration: int = 50,
        deceleration: int = 50,
    ) -> None:
        """
        设置真实机械臂的全局运动参数。
        
        对应 `embodied_internal._set_motion_params`，会影响 `c_a_j` 等函数。
        """
        embodied_internal = horizon_gateway.get_embodied_internal_module()
        embodied_internal._set_motion_params(
            max_speed=max_speed,
            acceleration=acceleration,
            deceleration=deceleration,
        )

    def get_motion_params(self) -> Dict[str, Any]:
        """
        获取当前全局运动参数（直接转发 embodied_internal._get_motion_params）。
        
        Returns:
            dict: {"max_speed": int, "acceleration": int, "deceleration": int}
        """
        embodied_internal = horizon_gateway.get_embodied_internal_module()
        return embodied_internal._get_motion_params()

    # ------------------------------------------------------------------
    # 摄像头 / 视觉相关辅助接口
    # ------------------------------------------------------------------

    def set_camera_id(self, camera_id: int) -> None:
        """
        设置用于具身智能 / 视觉抓取的摄像头 ID。

        对应 `embodied_internal._set_camera_id`。
        """
        embodied_internal = horizon_gateway.get_embodied_internal_module()
        embodied_internal._set_camera_id(camera_id)

    def set_current_camera_frame(self, frame: Any) -> None:
        """
        将当前摄像头画面传递给底层具身智能模块使用。
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

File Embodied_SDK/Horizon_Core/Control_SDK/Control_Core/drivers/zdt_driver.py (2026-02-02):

# -*- coding: utf-8 -*-
"""
ZDT驱动适配器

将现有的ZDTMotorController包装成符合MotorControllerInterface的适配器，
支持通过ProtocolInterface进行通信。

特点：
- 完全兼容现有ZDTMotorController的所有功能
- 支持通过protocol参数注入不同的通信协议
- 保持向后兼容性
"""

import logging
from typing import Optional
from ..interfaces.motor_interface import MotorControllerInterface
from ..interfaces.protocol_interface import ProtocolInterface
from ..motor_controller_ucp_simple import ZDTMotorController as _ZDTMotorControllerImpl


class ZDTDriverAdapter(MotorControllerInterface):
    """
    ZDT驱动适配器
    
    功能：
    - 实现MotorControllerInterface接口
    - 内部委托给ZDTMotorController实现
    - 支持ProtocolInterface注入
    
    使用示例：
    ----------
    方式1：通过工厂创建（推荐）
    ```python
    from Control_Core import create_motor_controller
    motor = create_motor_controller(motor_id=1, port="COM31", driver_type="zdt")
    ```
    
    方式2：直接创建
    ```python
    from Control_Core.protocols import UcpProtocol
    from Control_Core.drivers import ZDTDriverAdapter
    
    protocol = UcpProtocol(port="COM31", baudrate=115200)
    motor = ZDTDriverAdapter(motor_id=1, protocol=protocol)
    motor.connect()
    ```
    
    方式3：向后兼容（旧代码仍然可用）
    ```python
    from Control_Core import ZDTMotorController
    motor = ZDTMotorController(motor_id=1, port="COM31")  # 仍然支持
    ```
    """
    
    def __init__(self, motor_id: int, protocol: ProtocolInterface, **kwargs):
        """
        初始化ZDT驱动适配器
        
        Args:
            motor_id: 电机ID (1-255)
            protocol: 通信协议实例（如UcpProtocol）
            **kwargs: 其他参数（传递给底层实现）
        """
        self.motor_id = motor_id
        self.protocol = protocol
        self.logger = logging.getLogger(f"ZDTDriverAdapter[ID:{motor_id}]")
        
        # 创建底层实现（注入protocol的client）
        self._impl: Optional[_ZDTMotorControllerImpl] = None
        self._impl_kwargs = kwargs
    
    def _ensure_impl(self):
        """延迟初始化底层实现（避免connect前创建client）"""
        if self._impl is None:
            # 创建ZDTMotorController，但不自动连接
            self._impl = _ZDTMotorControllerImpl(
                motor_id=self.motor_id,
                port=getattr(self.protocol, 'port', 'N/A'),
                baudrate=getattr(self.protocol, 'baudrate', 115200),
                auto_connect=False,  # 不自动连接，由我们控制
                **self._impl_kwargs
            )
            
            # 注入protocol的client（如果protocol已连接）
            if hasattr(self.protocol, 'client') and self.protocol.is_connected():
                self._impl.client = self.protocol.client
                self._impl._connected = True
    
    # ==================== 连接管理 ====================
    
    def connect(self) -> None:
        """连接电机"""
        self._ensure_impl()
        
        # 先连接protocol
        if not self.protocol.is_connected():
            self.protocol.connect()
        
        # 将protocol的client注入到实现中
        if hasattr(self.protocol, 'client'):
            self._impl.client = self.protocol.client
            self._impl._connected = True
            self.logger.info(f"ZDT驱动适配器已连接 (motor_id={self.motor_id})")
        else:
            raise RuntimeError(f"协议 {type(self.protocol).__name__} 不支持client注入")
    
    def disconnect(self) -> None:
        """断开连接"""
        if self._impl:
            # 注意：不断开protocol，因为可能被其他电机共享
            self._impl._connected = False
            self.logger.info(f"ZDT驱动适配器已断开 (motor_id={self.motor_id})")
    
    @property
    def is_connected(self) -> bool:
        """检查是否已连接"""
        return self._impl is not None and self._impl._connected and self.protocol.is_connected()
    
    # ==================== 基本控制 ====================
    
    def enable(self) -> None:
        """使能电机"""
        self._ensure_impl()
        self._impl.enable()
    
    def disable(self) -> None:
        """失能电机"""
        self._ensure_impl()
        self._impl.disable()
    
    def stop(self) -> None:
        """立即停止"""
        self._ensure_impl()
        self._impl.stop()
    
    # ==================== 运动控制 ====================
    
    def move_to_position(self, position: float, speed: float, is_absolute: bool = True) -> None:
        """位置控制"""
        self._ensure_impl()
        self._impl.move_to_position(position=position, speed=speed, is_absolute=is_absolute)
    
    def move_to_position_trapezoid(self, position: float, max_speed: float, 
                                   acceleration: int, deceleration: int, 
                                   is_absolute: bool = True) -> None:
        """梯形曲线位置控制"""
        self._ensure_impl()
        self._impl.move_to_position_trapezoid(
            position=position,
            max_speed=max_speed,
            acceleration=acceleration,
            deceleration=deceleration,
            is_absolute=is_absolute
        )
    
    def set_speed(self, speed: float, acceleration: int = 1000) -> None:
        """速度控制"""
        self._ensure_impl()
        self._impl.set_speed(speed=speed, acceleration=acceleration)
    
    def set_torque(self, current: float, slope: int = 100) -> None:
        """力矩控制"""
        self._ensure_impl()
        self._impl.set_torque(current=current, slope=slope)
    
    # ==================== 状态读取 ====================
    
    def get_position(self) -> float:
        """读取当前位置（度）"""
        self._ensure_impl()
        return self._impl.get_position()
    
    def get_speed(self) -> float:
        """读取当前速度（RPM）"""
        self._ensure_impl()
        return self._impl.get_speed()
    
    def get_motor_status(self):
        """读取电机状态"""
        self._ensure_impl()
        return self._impl.get_motor_status()
    
    def get_temperature(self) -> float:
        """读取温度（°C）"""
        self._ensure_impl()
        return self._impl.get_temperature()
    
    def get_bus_voltage(self) -> float:
        """读取总线电压（V）"""
        self._ensure_impl()
        return self._impl.get_bus_voltage()
    
    def get_current(self) -> float:
        """读取电流（A）"""
        self._ensure_impl()
        return self._impl.get_current()
    
    def get_version(self) -> dict:
        """读取版本信息"""
        self._ensure_impl()
        return self._impl.get_version()
    
    # ==================== 回零功能 ====================
    
    def trigger_homing(self, mode: int = 4, **kwargs) -> None:
        """触发回零"""
        self._ensure_impl()
        # 兼容旧API的homing_mode参数
        if 'homing_mode' in kwargs:
            mode = kwargs.pop('homing_mode')
        self._impl.trigger_homing(mode=mode, **kwargs)
    
    def get_homing_status(self) -> dict:
        """读取回零状态"""
        self._ensure_impl()
        return self._impl.get_homing_status()
    
    def is_homing_complete(self) -> bool:
        """检查回零是否完成"""
        self._ensure_impl()
        return self._impl.is_homing_complete()
    
    # ==================== 其他功能 ====================
    
    def set_zero_position(self, save_to_chip: bool = True) -> None:
        """设置当前位置为零点"""
        self._ensure_impl()
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
